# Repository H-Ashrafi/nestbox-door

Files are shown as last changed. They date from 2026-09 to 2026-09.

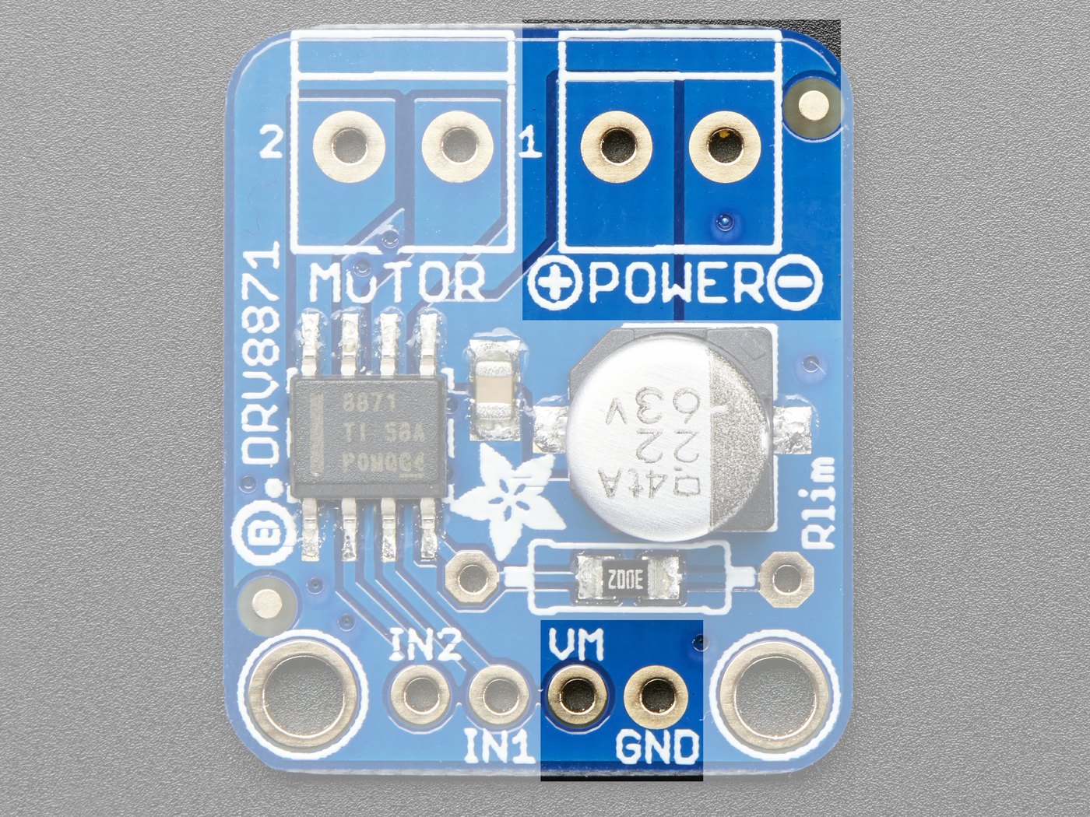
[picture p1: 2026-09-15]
docs/img/drv8871.jpg

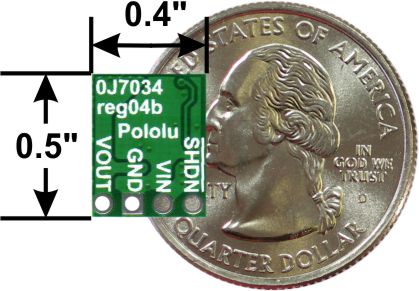
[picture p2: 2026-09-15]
docs/img/pololu.jpg

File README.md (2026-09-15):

# Nest box door

An automatic shutter for chicken nest boxes. It closes them mid-afternoon and opens
them again before dawn, so the hens lay in the boxes but can't sleep in them.

**Live page: https://h-ashrafi.github.io/nestbox-door/**

Battery only — no mains, no solar, no wi-fi. A XIAO ESP32-C3 works out today's
sunrise and sunset from the date and your latitude, and drives one 12 V linear
actuator that shuts every box at once.

## What's here

| Path | What it is |
|---|---|
| `docs/index.html` | The bench sheet, written for someone with no electronics background. Every part on the wiring diagram is clickable (photo, pinout, what to do with it), every technical word opens a plain-English explanation, and the resistors are drawn with their real colour bands. Styled with Tailwind from its public CDN. |
| `docs/nestbox-wiring.svg` | The wiring diagram. Clickable parts are `<g data-part="...">`. |
| `docs/nestbox-wiring.dxf` | Same drawing, AutoCAD R2000, 288 × 188 mm (A4 landscape). |
| `docs/nest-box-bench-sheet.html` | The whole page folded into one file — images, diagram and DXF inlined. Opens off a USB stick with no network. |
| `docs/nestbox-board.svg` | The perfboard layout: where every part sits on top, and every wire on the underside. |
| `make_wiring.py` | Generates the wiring SVG and the DXF from one geometry definition, so the drawing and the CAD file can't drift apart. |
| `make_board.py` | Generates the board layout SVG and `docs/board-wires.js`, the wire list the page renders. It validates the layout first and refuses to write anything if two parts want the same hole, if two modules overlap, if a wire ends in mid-air, or if a connection from the checklist is missing. |
| `bundle.py` | Folds `docs/index.html` into the single offline file. |

## Rebuilding

```
python make_wiring.py     # -> docs/nestbox-wiring.svg + .dxf
python make_board.py      # -> docs/nestbox-board.svg + docs/board-wires.js
python bundle.py          # -> docs/nest-box-bench-sheet.html
```

`bundle.py` uses Pillow to downscale oversized photos if it's installed, and works
without it. It also fetches the Tailwind script once and pastes it in, so the offline
file is styled with no network; run it with internet access.

## Bill of materials

Australian sourcing, every link checked 15 September 2026. **$372–$483** for the parts,
plus about $166 of tools if you own none. The full list with prices, links and a line on
why each thing is there is on the [bench sheet](https://h-ashrafi.github.io/nestbox-door/#parts).

**The four boards — $46.15, one order from Core Electronics**

| Part | Price | Link |
|---|---|---|
| Seeed XIAO ESP32-C3 | $10.65 | [Core Electronics](https://core-electronics.com.au/seeed-studio-xiao-esp32c3-tiny-mcu-board-with-wi-fi-and-ble-battery-charge-supported-power-efficiency-and-rich-interface.html) |
| DS3231M MEMS RTC (DFRobot DFR0641) | $11.75 | [Core Electronics](https://core-electronics.com.au/ds3231m-mems-precise-rtc.html) |
| Adafruit DRV8871 motor driver | $13.80 | [Core Electronics](https://core-electronics.com.au/adafruit-drv8871-dc-motor-driver-breakout-board-3-6a-max.html) |
| Pololu D36V6F5 5 V buck | $9.95 | [Core Electronics](https://core-electronics.com.au/pololu-5v-600ma-step-down-voltage-regulator-d36v6f5.html) |

**Power — $74.00**

| Part | Price | Link |
|---|---|---|
| 12 V 7.2 Ah SLA battery | ≈$34.95 | [Jaycar SB2486](https://www.jaycar.com.au/12v-7-2ah-sla-back-up-battery-nbn-alarm-ufb/p/SB2486), or [$38.98 Amazon AU](https://www.amazon.com.au/dp/B0G6K9KNLK) |
| 12 V 1 A automatic SLA charger | $32.95 | [Jaycar MB3619](https://www.jaycar.com.au/12v-1a-sla-battery-charger/p/MB3619). **Jaycar wins** — the [NOCO GENIUS1](https://www.amazon.com.au/dp/B08D6WV445) is $70.95 and adds nothing for one small battery |
| Inline blade fuse holder, water resistant | $4.95 | [Jaycar SZ2042](https://www.jaycar.com.au/30a-32vdc-water-resistant-inline-standard-blade-fuse-holder/p/SZ2042) |
| 2 A blade fuse | $1.15 | [Jaycar SF2127](https://www.jaycar.com.au/2a-grey-standard-blade-fuse/p/SF2127) — separate line, the holder comes empty |

**The moving part — $108–$220**

| Part | Price | Link |
|---|---|---|
| 12 V linear actuator, 300 mm, limit switches | $88.42 | [Justech, Amazon AU](https://www.amazon.com.au/dp/B0F6TV1ZVJ) — IP54, 6 mm/s, brackets included |
| …or the weatherproof one | $199.69 | [Motion Dynamics, IP65](https://www.motiondynamics.com.au/linear-actuator-300mm-stroke-20mm-sec-12v-400n-clevis-end.html) — worth it if rain reaches the actuator |
| Cord, pulley, two eye bolts, turnbuckle | ≈$20 | any hardware shop |

**Loose components — $39.14**

| Part | Price | Link |
|---|---|---|
| Resistor pack, 300 pieces (has 220k, 33k, 10k) | $12.95 | [Jaycar RR1680](https://www.jaycar.com.au/1-4-watt-carbon-film-resistors-300-pieces/p/RR1680) |
| 100 nF monolithic capacitor | $0.35 | [Jaycar RC5490](https://www.jaycar.com.au/100nf-50vdc-monolithic-capacitor/p/RC5490) |
| CR1220 coin cell (for the clock) | $4.95 | [Jaycar SB2527](https://www.jaycar.com.au/cr1220-3v-lithium-battery/p/SB2527) |
| Male header, 2.54 mm, 1×40 — buy two | $0.45 ea | [Core Electronics CE07828](https://core-electronics.com.au/male-pin-header-2-54mm-1x40.html) |
| Double-sided perfboard kit, 32 pcs (has the 7×9 cm board) | $19.99 | [Elegoo, Amazon AU](https://www.amazon.com.au/dp/B0772FK81G) — plain perfboard, **not** stripboard |

**The box and the wire — $104.51**

| Part | Price | Link |
|---|---|---|
| Sealed IP65 ABS enclosure, 171×121×80 | $24.95 | [Jaycar HB6129](https://www.jaycar.com.au/sealed-abs-enclosure-171-x-121-x-80mm/p/HB6129) |
| PG7 cable glands, 20 pack | $20.00 | [Amazon AU](https://www.amazon.com.au/Cable-Lokman-Plastic-Waterproof-Adjustable/dp/B06Y5HGYK2), or [2 pack from Jaycar, $5.95](https://www.jaycar.com.au/3-6-5mm-dia-waterproof-cable-glands-pack-of-2/p/HP0720) |
| 18 AWG 2-core red/black, 12 m | $14.61 | [Amazon AU](https://www.amazon.com.au/dp/B01LZRV0HV) |
| Hook-up wire, 8 colours, 26 AWG | $39.95 | [Jaycar WH3009](https://www.jaycar.com.au/light-duty-hook-up-wire-pack-8-colours/p/WH3009) |
| Cable ties | ≈$5 | any hardware shop |

Tools are listed separately on the [bench sheet](https://h-ashrafi.github.io/nestbox-door/#tools),
priced both ways — Jaycar and Amazon AU.

## Two things that bite

- **D0, D8 and D9 on the XIAO are strapping pins.** A pull-down on any of them and
  the board won't boot. IN1 and IN2 go to D1 and D3 instead.
- **Drive the panel through a cord, never a rigid link.** The actuator only ever
  lifts; gravity closes the door. Bolted straight on it pushes 100 N onto whatever
  is underneath it.

## Credits

Board photos are the manufacturers' own — [Seeed](https://wiki.seeedstudio.com/XIAO_ESP32C3_Getting_Started/),
[Adafruit](https://learn.adafruit.com/adafruit-drv8871-brushed-dc-motor-driver-breakout/pinouts),
[Pololu](https://www.pololu.com/product/3792), [DFRobot](https://wiki.dfrobot.com/dfr0641/) —
reproduced for reference while building, with attribution on each.

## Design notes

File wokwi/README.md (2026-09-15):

# Run the circuit before you build it

[Wokwi](https://wokwi.com) is a free circuit simulator that runs in a browser. It
shows real pictures of the boards with coloured wires between the pins, you can
drag things around and pull wires yourself, and it runs the actual firmware.

You do not need an account to run it. You need one only if you want to save it.

## Getting it going — five steps

1. Go to **https://wokwi.com/projects/new/esp32-c3**
2. Click the **diagram.json** tab. Select everything that's there and delete it.
   Paste in the whole of `diagram.json` from this folder.
3. Click the **sketch.ino** tab. Same again — select all, delete, paste in
   `sketch.ino` from this folder.
4. Click **Library Manager**, then the **+** button, and add these three:
   `RTClib`, `Dusk2Dawn`, `ESP32Servo`.
5. Press the green **▶** play button. First build takes a minute or so.

## What you're looking at

| On screen | On the real board |
|---|---|
| The black ESP32-C3 stick | Your XIAO ESP32-C3 |
| The small blue board with the coin cell | The DS3231M clock |
| **Green LED** lit | The driver is running the motor **open** |
| **Red LED** lit | The driver is running the motor **shut** |
| The servo horn | Where the nest box door actually is |
| The knob | Battery voltage — the 220k / 33k divider |
| The two 10 kΩ resistors | The same two pull-downs, doing the same job |

The GPIO numbers are identical to the real build, so you can hold this next to
[the wiring diagram](https://h-ashrafi.github.io/nestbox-door/) and they match
pin for pin:

```
GPIO3 = XIAO D1 = driver IN1      GPIO6 = XIAO D4 = clock SDA
GPIO5 = XIAO D3 = driver IN2      GPIO7 = XIAO D5 = clock SCL
GPIO4 = XIAO D2 = battery sense
```

## Things to try

- **Just watch it.** One day passes every 30 seconds or so. The green LED flashes
  at dawn, the red one flashes mid-afternoon, and the servo swings between them.
  The serial window prints what it's doing and why, in plain English.
- **Turn the knob down.** Below 11.9 V the battery guard fires: it parks the
  boxes open and stops moving. That's the behaviour that stops a flat battery
  leaving your hens locked out.
- **Change `LAT` to `-12.46`** (Darwin) **and watch the window barely move** all
  year. Then try `-42.88` (Hobart) and watch it swing hard between seasons. That
  is the whole reason the controller works off sunrise rather than a clock time.
- **Pull a wire out** and see what breaks. Free, and it costs you nothing.

## What it can't tell you

The simulator proves the *logic*. It cannot catch a swapped VIN and VOUT on the
buck, a cold solder joint, or a pull-down on a strapping pin stopping the board
booting. Those are the failures that actually bite, and they're all physical —
which is what section 06 of the bench sheet, "build it in stages", is for.

There is no DRV8871 or linear actuator in Wokwi's parts library. That matters
less than it sounds: the driver is just *two pins going high and low*, and two
LEDs show that perfectly.

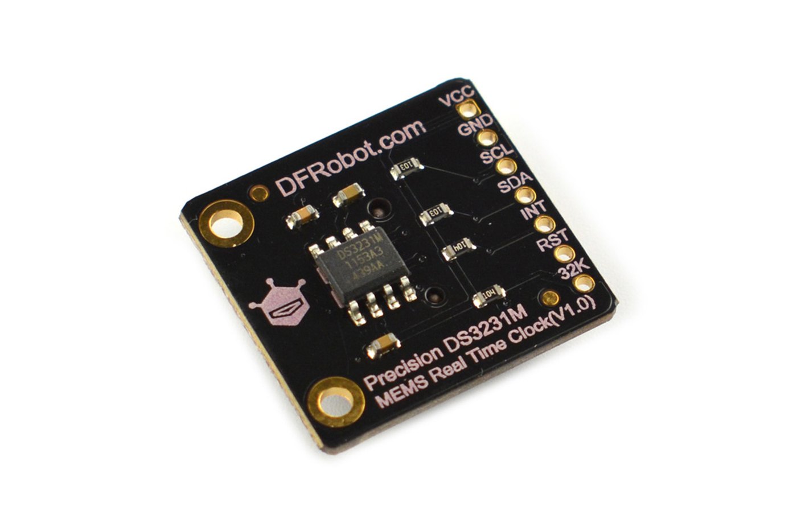
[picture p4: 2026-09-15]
docs/img/ds3231m.jpg

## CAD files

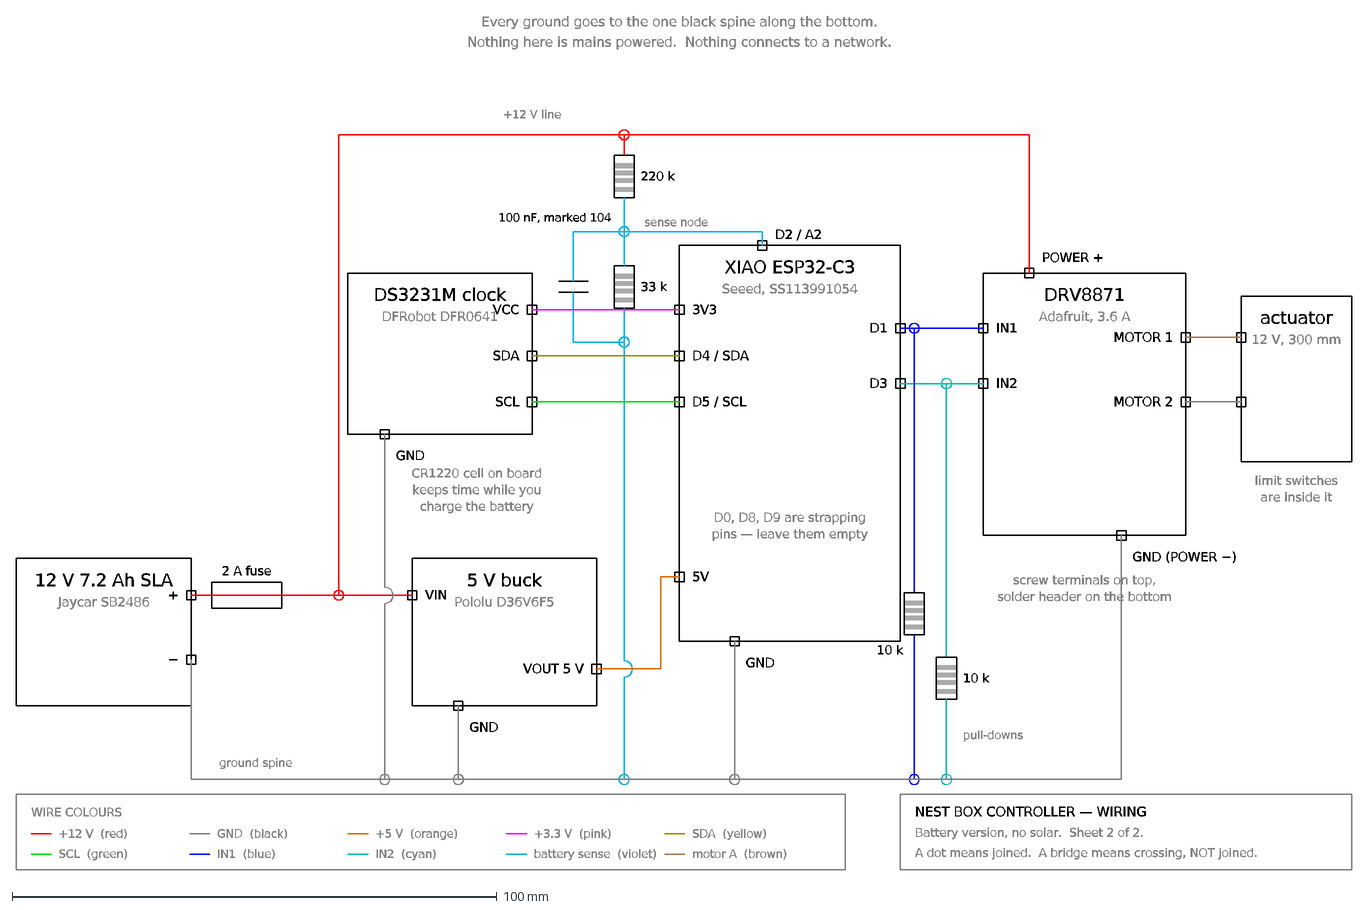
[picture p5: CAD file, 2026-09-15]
docs/nestbox-wiring.dxf
12 V 7.2 Ah SLA
Jaycar SB2486
+
−
2 A fuse
5 V buck
Pololu D36V6F5
VIN
VOUT 5 V
GND
DS3231M clock
DFRobot DFR0641
VCC
SDA
SCL
CR1220 cell on board
keeps time while you
charge the battery
XIAO ESP32-C3
Seeed, SS113991054
3V3
D4 / SDA
D5 / SCL
5V
D2 / A2
D1
D3
D0, D8, D9 are strapping
pins — leave them empty
DRV8871
Adafruit, 3.6 A
POWER +
IN1
IN2
GND (POWER −)
MOTOR 1
MOTOR 2
screw terminals on top,
solder header on the bottom
actuator
12 V, 300 mm
limit switches
are inside it
220 k
33 k
100 nF, marked 104
sense node
10 k
pull-downs
ground spine
+12 V line
WIRE COLOURS
+12 V (red)
GND (black)
+5 V (orange)
+3.3 V (pink)
SDA (yellow)
SCL (green)
IN1 (blue)
IN2 (cyan)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

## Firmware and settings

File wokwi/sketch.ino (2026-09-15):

// ── NEST BOX DOOR — SIMULATOR VERSION ───────────────────────────────
// This is the real controller logic with four swaps, so you can SEE it run:
//
//   real DS3231M clock   ->  Wokwi's DS1307   (same I2C address; one word changes)
//   real DRV8871 driver  ->  two LEDs         (they show exactly what IN1/IN2 do)
//   real linear actuator ->  a servo          (so you can watch the door move)
//   real deep sleep      ->  a fast clock     (one whole day every ~30 seconds)
//
// The sunrise maths, the schedule and the battery guard are the same code
// that goes on the real board. The pin numbers are the same GPIOs too:
//   GPIO3 = XIAO D1 = IN1      GPIO5 = XIAO D3 = IN2
//   GPIO4 = XIAO D2 = battery sense
//   GPIO6 = XIAO D4 = SDA      GPIO7 = XIAO D5 = SCL

#include <Wire.h>
#include <RTClib.h>
#include <Dusk2Dawn.h>
#include <ESP32Servo.h>

const float LAT = -37.8136;     // your latitude  (south = negative)
const float LON = 144.9631;     // your longitude (east  = positive)
const float TZ  = 10.0;         // STANDARD time offset. Never change for daylight saving.

const int OPEN_BEFORE_SUNRISE_MIN = 30;    // boxes open 30 min before sunrise
const int CLOSE_BEFORE_SUNSET_MIN = 150;   // boxes shut 2.5 h before sunset
const float VBAT_CUTOFF = 11.9;            // volts: below this, stop moving

const int PIN_IN1 = 3, PIN_IN2 = 5, PIN_VBAT = 4, PIN_SERVO = 10;

const int MIN_PER_TICK = 6;     // simulated minutes per loop
const int TICK_MS      = 120;   // real milliseconds per loop

RTC_DS1307 rtc;                 // real build: RTC_DS3231 rtc;
Dusk2Dawn here(LAT, LON, TZ);
Servo panel;

DateTime clk;
int lastState = -1;

// The knob stands in for the 220k / 33k divider on the real board.
float batteryVolts() {
  return 10.5 + (analogRead(PIN_VBAT) / 4095.0) * 3.5;   // 10.5 V .. 14.0 V
}

void driveMotor(bool opening) {
  digitalWrite(PIN_IN1, opening ? HIGH : LOW);
  digitalWrite(PIN_IN2, opening ? LOW  : HIGH);
  panel.write(opening ? 90 : 0);
  delay(700);                    // stands in for the actuator's 55 second stroke
  digitalWrite(PIN_IN1, LOW);    // both low = driver coasts, LEDs go out
  digitalWrite(PIN_IN2, LOW);
}

void setup() {
  Serial.begin(115200);
  pinMode(PIN_IN1, OUTPUT);
  pinMode(PIN_IN2, OUTPUT);
  digitalWrite(PIN_IN1, LOW);
  digitalWrite(PIN_IN2, LOW);
  panel.attach(PIN_SERVO, 500, 2400);
  panel.write(0);

  Wire.begin(6, 7);
  if (!rtc.begin()) { Serial.println("No clock found - check SDA and SCL."); while (1) delay(10); }
  clk = DateTime(2026, 9, 15, 0, 0, 0);

  Serial.println();
  Serial.println("NEST BOX DOOR - simulator");
  Serial.println("-------------------------------------------------------------");
  Serial.println("green LED  the driver is running the motor OPEN");
  Serial.println("red LED    the driver is running the motor SHUT");
  Serial.println("servo      where the door actually is");
  Serial.println("the knob   battery volts - turn it down past 11.9 V to see");
  Serial.println("           the guard park the boxes open and give up");
  Serial.println();
  Serial.println("One whole day passes every 30 seconds or so.");
  Serial.println("-------------------------------------------------------------");
  Serial.println();
}

void loop() {
  clk = clk + TimeSpan(0, 0, MIN_PER_TICK, 0);
  int minuteOfDay = clk.hour() * 60 + clk.minute();

  int sunrise = here.sunrise(clk.year(), clk.month(), clk.day(), false);
  int sunset  = here.sunset (clk.year(), clk.month(), clk.day(), false);
  int openAt  = sunrise - OPEN_BEFORE_SUNRISE_MIN;
  int closeAt = sunset  - CLOSE_BEFORE_SUNSET_MIN;

  float vbat = batteryVolts();
  int want = (minuteOfDay >= openAt && minuteOfDay < closeAt) ? 1 : 0;

  if (vbat < VBAT_CUTOFF) {
    if (lastState != 1) {
      Serial.printf("%02d:%02d  battery %.1f V - too flat. Parking the boxes OPEN and stopping.\n",
                    clk.hour(), clk.minute(), vbat);
      driveMotor(true);
      lastState = 1;
    }
  } else if (want != lastState) {
    Serial.printf("%02d:%02d  %s\n", clk.hour(), clk.minute(),
      want ? "OPENING  - hens can get in to lay" : "SHUTTING - before they pick a roost");
    Serial.printf("        sunrise %02d:%02d, sunset %02d:%02d, battery %.1f V\n",
      sunrise / 60, sunrise % 60, sunset / 60, sunset % 60, vbat);
    driveMotor(want == 1);
    lastState = want;
  }

  if (clk.minute() < MIN_PER_TICK && clk.hour() % 6 == 0) {
    Serial.printf("%02d:%02d  %s\n", clk.hour(), clk.minute(),
                  lastState == 1 ? "boxes open" : "boxes shut");
  }

  delay(TICK_MS);
}

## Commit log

2026-09-15 Nest box door: sunrise/sunset controller, wiring drawing and bench sheet
    Battery-powered XIAO ESP32-C3 that works out local sunrise and sunset from the
    date and a latitude, then drives one 12 V linear actuator to shut every nest
    box at once. No mains, no solar, no wi-fi.
    make_wiring.py emits the SVG and the DXF from a single geometry definition, so
    the drawing and the CAD file cannot drift apart. bundle.py folds the page into
    one offline file with the photos and the diagram inlined.
    Claude-Session: https://claude.ai/code/session_01LMVaud3fQK2oS5RUBawfVa
    [nestbox-wiring.dxf]
2026-09-15 Price the tools list both ways: Jaycar and Amazon AU
    Every Jaycar line now carries a verified Amazon AU alternative with its ASIN,
    current price and star rating, and the cheaper of the two is marked. Amazon is
    about $40 better over the whole list, but Jaycar still wins on the soldering
    station, the protoboard, the header strips and the battery charger - so say so
    rather than pretending one shop wins everything.
    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
2026-09-15 Add a runnable Wokwi simulation of the controller
    wokwi/diagram.json and wokwi/sketch.ino drop into a new ESP32-C3 project and
    run the real scheduling logic, with four swaps so it is visible: DS1307 in
    place of the DS3231M (same I2C address), two LEDs in place of the DRV8871, a
    servo in place of the actuator, and a fast clock in place of deep sleep. GPIO
    numbers match the real build pin for pin, so it reads against the wiring
    diagram directly.
    diagram.json verified to load and render in Wokwi - every pin name accepted.
    The sketch has not been through a successful build yet; Wokwi free build queue
    was backed up past 90 seconds when this was committed.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
    [sketch.ino]
2026-09-15 Rewrite the bench sheet for a total beginner
    Every technical word is now clickable and opens a plain-English explanation,
    the battery sense divider gets its own illustrated section, resistors are
    drawn with their real colour bands (on the page and on the wiring diagram),
    every sentence has a verb, and the page moves to a white/teal Tailwind look.
    The pull-downs, ground spine and 12 V line are clickable on the diagram, and
    bundle.py inlines the Tailwind script so the offline file works with no network.
    [nestbox-wiring.dxf]
2026-09-15 Board drawings with live pin highlighting in every pop-up; coin cell and chip-vs-board glossary entries
    Each board pop-up now shows a drawing of the board with its pins beside the text.
    Hovering or tapping a pin name in the text lights that pin up on the drawing. The
    same drawings sit beside the tables in the boards section.
2026-09-15 Add a complete parts list with verified links and prices
    The page only priced tools. It now has a "Buy the parts" section covering
    everything that ends up in the finished controller: the four boards, the
    battery, charger, fuse holder and fuse, the actuator and its cord, the
    resistors, capacitor, coin cell, headers and protoboard, and the enclosure,
    glands and wire. Every link was fetched and every price read off the live
    page on 15 September 2026.
    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
2026-09-15 Fix the menu hiding sections off the right edge
    Below about 900px the menu scrolled sideways with its scrollbar hidden, so
    Shopping list, Tools and Glossary fell off the edge with nothing to show they
    were there. Narrow screens now get a Jump to dropdown listing every section,
    and wide screens get the full row, wrapping rather than scrolling, with the
    two shopping entries set apart and the current section highlighted.
    Also adds a Go to the shopping list button in the header, so the list is
    reachable without the menu at all.
2026-09-15 Add a board layout guide, and fix the perfboard in the parts list
    New "board layout" section: a top view showing where each module and each
    loose component sits on a 70 x 90 mm perfboard, and an underside view,
    flipped left to right, with all 21 wires colour coded by net. Holes are
    named by column letter and row number, and the wire list under the drawing
    is a tick-off table that remembers its ticks.
    make_board.py generates both the drawing and the wire list from one layout
    definition, and validates before writing: no two parts in one hole, no two
    modules overlapping, no wire ending in mid-air, and every connection from
    the checklist present in the layout.
    The parts list named the Jaycar H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
